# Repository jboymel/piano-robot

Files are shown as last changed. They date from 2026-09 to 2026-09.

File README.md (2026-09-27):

# Modular Robotic Actuation System for Piano Key Control

**A modular, clamp-on solenoid system that plays an acoustic piano from a MIDI score. Scaled from a one-octave prototype to a 7-octave (84-key) array of daisy-chained driver boards.**

Northwestern University · Summer Undergraduate Research Grant (SURG) 2026
Jordan Boymel · Advisor: Dr. Brenna Argall, Assistive & Rehabilitation Robotics Lab, Shirley Ryan AbilityLab

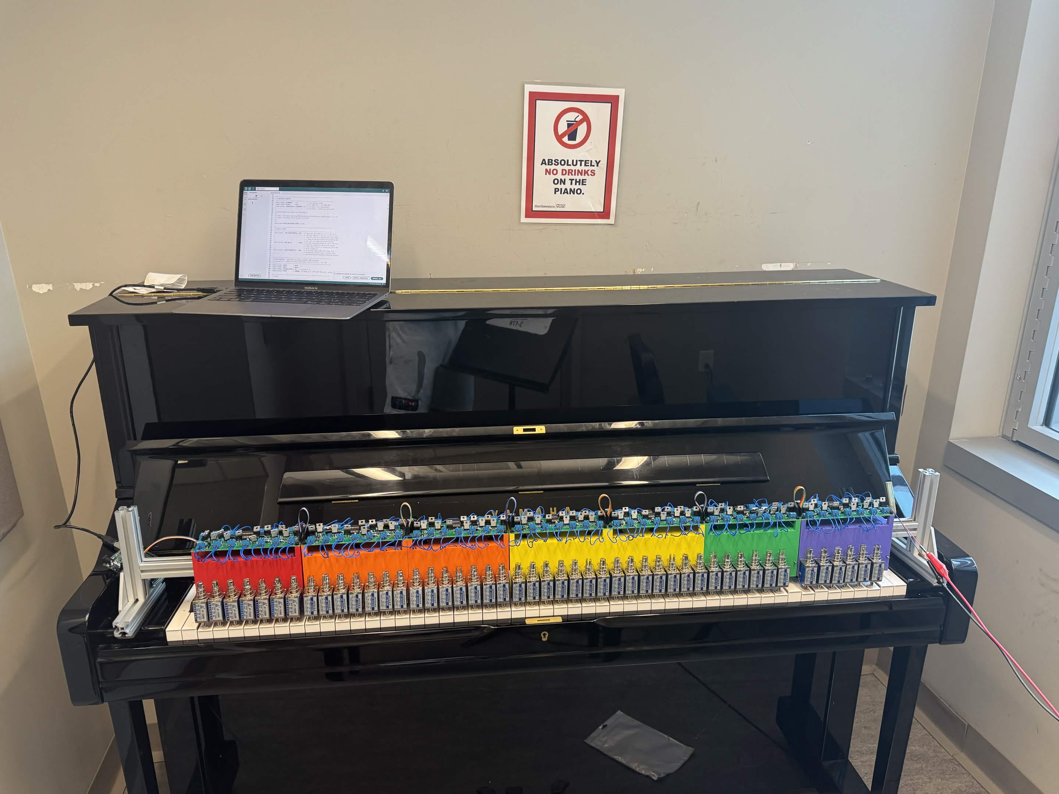
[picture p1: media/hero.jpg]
Robot mounted on the piano


> **Status (Sept 2026): hardware, firmware, and host software complete; full-scale tuning paused.**
> The whole pipeline, from MIDI to solenoids, runs. The final demo used a lower-rated 24 V supply because the main supply couldn't be wired properly, and several actuators strike inconsistently. See [Current status and known issues](#current-status-and-known-issues).

---

## Why

Self-playing pianos are purpose-built, expensive instruments. This project asks whether a modular attachment can turn an ordinary piano into a music-making machine instead. It is motivated by making piano playing accessible to people with motor disabilities, and by the number of acoustic pianos that sit unused.

## What I built

| Area | What it is |
|---|---|
| **Driver electronics** | Custom 2-layer KiCad PCB, one per octave: 12 low-side MOSFET channels, flyback protection, and a shift-register serial interface. Boards daisy-chain for power and signal. |
| **Actuation** | 24 V push-pull solenoids (one per key) with a threaded felt-tipped striker |
| **Mechanical** | Parametric Onshape bracket that straddles 80/20 T-slot extrusion over the keybed. Key pitch was measured on a real piano. |
| **Firmware** | Arduino Mega sketch that receives full keyboard state over USB serial and clocks it to the shift-register chain, with safety interlocks |
| **Host software** | Python player that reads a MuseScore MIDI export, compensates for actuator latency, and streams frames to the Arduino |

## System architecture

The Arduino connects to the whole 84-key array through five wires: 5 V, GND, DATA (pin 51), CLOCK (pin 52), and LATCH (pin 8).

## Hardware

### Octave driver board

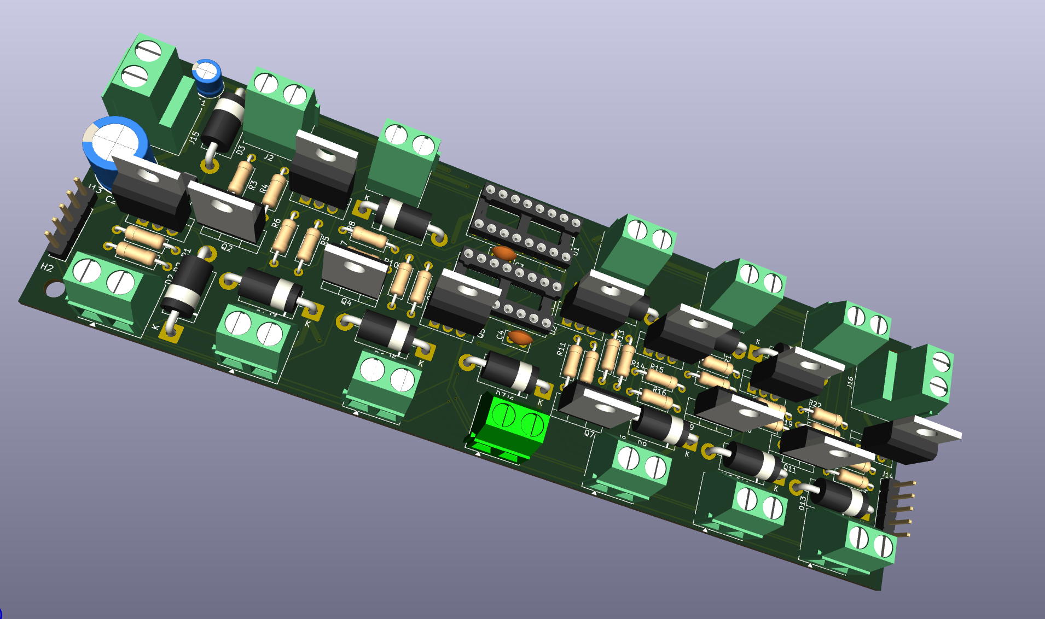
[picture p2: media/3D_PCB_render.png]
Octave driver board


- **163.8 × 52.4 mm**, 2-layer. Four M3 mounting holes on a 155.8 × 44.4 mm pattern.
- **Two 74HC595 shift registers** per board, in DIP sockets and cascaded (U1 QH′ → U2 SER). 12 of 16 outputs are used. SRCLR is tied high and OE is tied low.
- **12 × IRLZ44N** logic-level MOSFETs (55 V V<sub>DS</sub>), low-side switching, TO-220 mounted vertically to save board depth.
- **FR307 flyback diode** across each solenoid, and an SMBJ28A TVS diode for transient protection.
- Each MOSFET gate has a 220 Ω and a 10 kΩ resistor.
- GND pour on B.Cu and +24 V on F.Cu. Trace widths sized to IPC-2152 for solenoid current.
- **Power in/out:** screw terminals J15 → J16 pass the 24 V bus board-to-board on heavy wire. Logic signals chain separately on a 5-conductor ribbon.
- First spin fabricated by JLCPCB. Seven boards assembled.

### Actuators and strikers
- **JF-1039B** push-pull solenoid: 25 N, 10 mm stroke, about 400 mA at 24 V.
- **Striker:** an M4 × 0.7 coupling nut threads onto the plunger, with a 3/8″ felt pad on the contact face to protect the keys and soften the attack.

### Mounting bracket
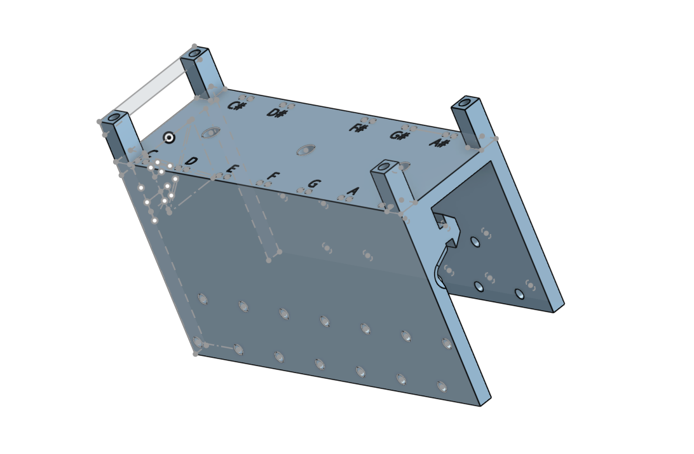
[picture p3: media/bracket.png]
Parametric bracket


- An asymmetric inverted-U saddle that straddles 80/20 T-slot extrusion. It is fully parametric in Onshape.
- Key pitch was measured on a real piano and adjusted from 23.4 mm to about 23.5 mm. The standoff inset is a parameter, so the bracket stays compatible with the PCB hole pattern.

### Power
- **24 V solenoid bus:** a single 1500 W (62.5 A) switching supply, chained board-to-board.
- **5 V logic:** supplied from the laptop over the Arduino's USB connection and carried to every board on the signal ribbon.
- All grounds are common.

## Firmware and control

### Serial protocol (host → Arduino)

| Field | Bytes | Value |
|---|---|---|
| Sync | 2 | `0xAA 0x55` |
| Key state | 11 | 84 bits, one per key (1 = energized) |
| Checksum | 1 | XOR |

Sent at 250000 baud. Every frame carries the full keyboard state. The Arduino never has to reconstruct note-on/note-off history, so a dropped frame is simply replaced by the next one.

### Safety limits (firmware)

| Limit | Value | Purpose |
|---|---|---|
| `MAX_SIMULTANEOUS` | 20 keys | Caps solenoid current at about 8 A |
| `MAX_ON_MS` | 5000 ms | Releases any key held too long, which protects the coils from overheating |
| `LINK_TIMEOUT_MS` | 500 ms | Releases all keys if the host stops sending valid frames |

### Latency compensation (host)
Measured strike latency is about 50 ms from energize to key contact. `musescore_player.py` schedules every note `ATTACK_LATENCY_MS` (≈50 ms) early so strikes land on the beat. It also enforces `MINIMUM_STRIKE_HOLD_MS` (≈10 ms) so very short notes still fully depress the key.

The latency also sets a mechanical limit: repeated notes on the same key top out around sixteenth notes at 95–100 BPM.

## Design evolution

The project started as a one-octave bench prototype focused on characterizing a single key. The table lists the major changes on the way to 84 keys.

| Change | Why |
|---|---|
| One Arduino pin per key → **74HC595 shift-register chain** | 84 keys can't each get a pin. Three signal lines now drive any number of boards. |
| IRLB8721 (30 V) → **IRLZ44N (55 V)** | More drain-voltage margin against inductive switching transients on a 24 V rail |
| 3-tier PCB stack → **2 tiers** | The FSR circuit was confirmed as instrumentation only, not part of the production drive path |
| One large board → **one PCB per octave, daisy-chained** | Identical boards are cheaper to fabricate, easier to debug, and scale to any number of octaves |
| Key pitch 23.4 mm → **≈23.5 mm** | Measured on a real piano. The error accumulates across an octave. |

Peer review of the schematics caught wiring errors before fabrication, including flyback diode polarity and MOSFET pinout.

## Current status and known issues

**Works**
- Seven octave boards assembled and running on one chain.
- Firmware, serial protocol, and safety limits are working.
- The Python player drives the array from MuseScore MIDI.
- The shift-register chain was validated with indicator LEDs before solenoids were connected.

**Resolved**
- **Chain failure when scaling from 3 to 7 boards.** The symptoms looked like a power-budget problem, but the cause was one shift register seated backwards in its socket. Write-up: [docs/power-debugging.md](docs/power-debugging.md).

**Known issues**
1. **Demo run on an underpowered 24 V supply.** The main 1500 W supply couldn't be wired in time for the final demo because the right-gauge wire was missing, so a lower-rated supply stood in.
2. **Inconsistent strikes on some actuators.** Not yet diagnosed. An under-supplied 24 V rail (issue 1) is the first suspect. Solenoid, striker, or mounting variation still has to be ruled out once the main supply is connected.

<!-- MEDIA: even an imperfect clip is worth including. Label it honestly, e.g.
**Demo (Sept 2026, reduced-power supply):** [video](media/demo.mp4)
-->

## Next steps
- Wire in the main 24 V supply and re-test all 84 channels.
- Diagnose the inconsistent actuators channel by channel (current draw, stroke, striker seating).
- Quantify timing and force consistency. The original proposal set targets (mean onset error under 10 ms, standard deviation under 5 ms, force coefficient of variation under 15%) and planned an FSR 402 and TCST2103 photointerrupter rig to measure them. That rig was prototyped on the bench but not used in the final build, and no characterization data has been collected yet.
- Record a clean full-keyboard demo.

## Lessons learned
- **Check the assembly before redesigning the system.** The failure at 7 boards looked like a supply problem, and I had started planning a separate 5 V supply. The actual cause was one reversed IC.
- **Scale in steps and test at each one.** Adding boards incrementally narrowed the fault to the new part of the chain.
- **Design reviews pay for themselves.** Wiring errors were caught on paper instead of on a powered board.

## Repository layout

```
firmware/
  piano_driver/        piano_driver.ino: Arduino Mega sketch (serial → shift-register chain)
  bench_test/          serial_logger.py: logger from the single-key bench prototype
host/                  midi_player.py: MIDI file → serial key-state frames
hardware/
  pcb/                 KiCad project (solenoid-driver-v2) and fabrication Gerbers (.zip)
cad/
  stl/                 bracket.stl
matlab/analysis/       analyze_trials.m: trial statistics (onset time, force)
docs/                  BOM, wiring, schematic PDF, chain-failure write-up
media/                 Photos, KiCad render, test videos
```

> `matlab/analysis/analyze_trials.m` generates **placeholder data** if no real trial CSV is present. Any plots it produces without real data are not results.

## Bill of materials and wiring
- [Bill of materials](docs/bom.md)
- [Prototype bench wiring](docs/wiring.md)
- [Debugging the 7-board chain failure](docs/power-debugging.md)

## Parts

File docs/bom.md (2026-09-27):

# Bill of materials

## Per octave driver board (×7)

| Item | Spec | Qty per board |
|---|---|---|
| Octave driver PCB | 2-layer, 163.8 × 52.4 mm (JLCPCB) | 1 |
| 74HC595 shift register (U1, U2) | 8-bit SIPO, DIP-16 | 2 |
| IRLZ44N MOSFET (Q1–Q12) | TO-220, logic-level, 55 V V<sub>DS</sub>, mounted vertically | 12 |
| DIP-16 socket | For U1, U2 | 2 |
| FR307 flyback diode (D2–D13) | 3 A fast recovery, DO-201AD | 12 |
| SMBJ28A TVS diode (D1) | 28 V standoff, SMB (the only SMD part) | 1 |
| Resistor, 220 Ω | Axial, one per MOSFET gate | 12 |
| Resistor, 10 kΩ | Axial, one per MOSFET gate | 12 |
| Capacitor, 1000 µF (C2) | Electrolytic, radial 10 mm | 1 |
| Capacitor, 10 µF (C1) | Electrolytic, radial 5 mm | 1 |
| Capacitor, 0.1 µF (C3, C4) | Ceramic disc | 2 |
| Screw terminal, solenoid (J1–J12) | Phoenix MKDS 1,5 style, 2-pos, 5.08 mm | 12 |
| Screw terminal, power (J15, J16) | Phoenix MKDS 3 style, 2-pos, 5.08 mm; 24 V / GND in and out | 2 |
| 1×5 pin header (J13, J14) | 2.54 mm; 5 V · GND · DATA · CLOCK · LATCH in and out | 2 |
| JF-1039BS solenoid | 24 V push-pull, 25 N, 10 mm stroke, ~400 mA | 12 |
| M4 × 0.7 coupling nut | Round, 10 mm, female-female (striker) | 12 |
| Felt pad | 3/8″ adhesive dot (striker face) | 12 |

## System

| Item | Spec | Qty |
|---|---|-----|
| 24 V switching PSU | 1500 W, 62.5 A | 1 |
| Arduino Mega 2560 | USB-powered; also supplies 5 V logic to all boards | 1 |
| 80/20 1010 T-slot extrusion | Frame rail | as needed |
| Bracket | Parametric, 3D-printed PLA | as needed |
| Silicone protection | Applied to the frame | as needed |

## Prototype bench only (not used in the final build)

| Item | Spec | Qty |
|---|---|-----|
| FSR 402 | Force sensing resistor | 2 |
| TCST2103 | Slotted photointerrupter (onset timing) | 6 |

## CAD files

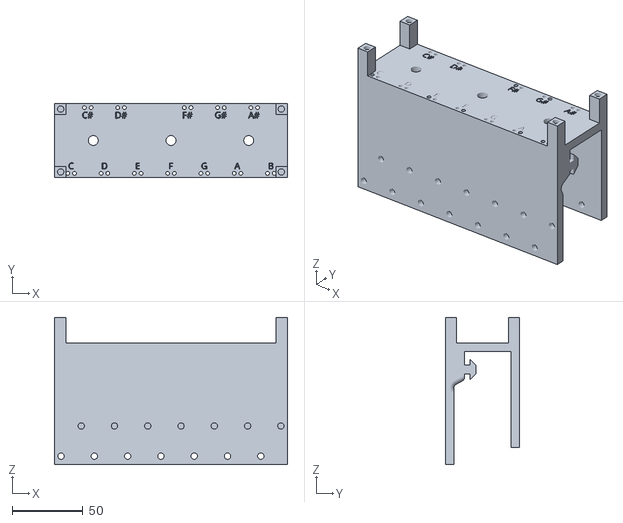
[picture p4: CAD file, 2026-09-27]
cad/stl/bracket.stl
164.5 x 52.4 x 104.0

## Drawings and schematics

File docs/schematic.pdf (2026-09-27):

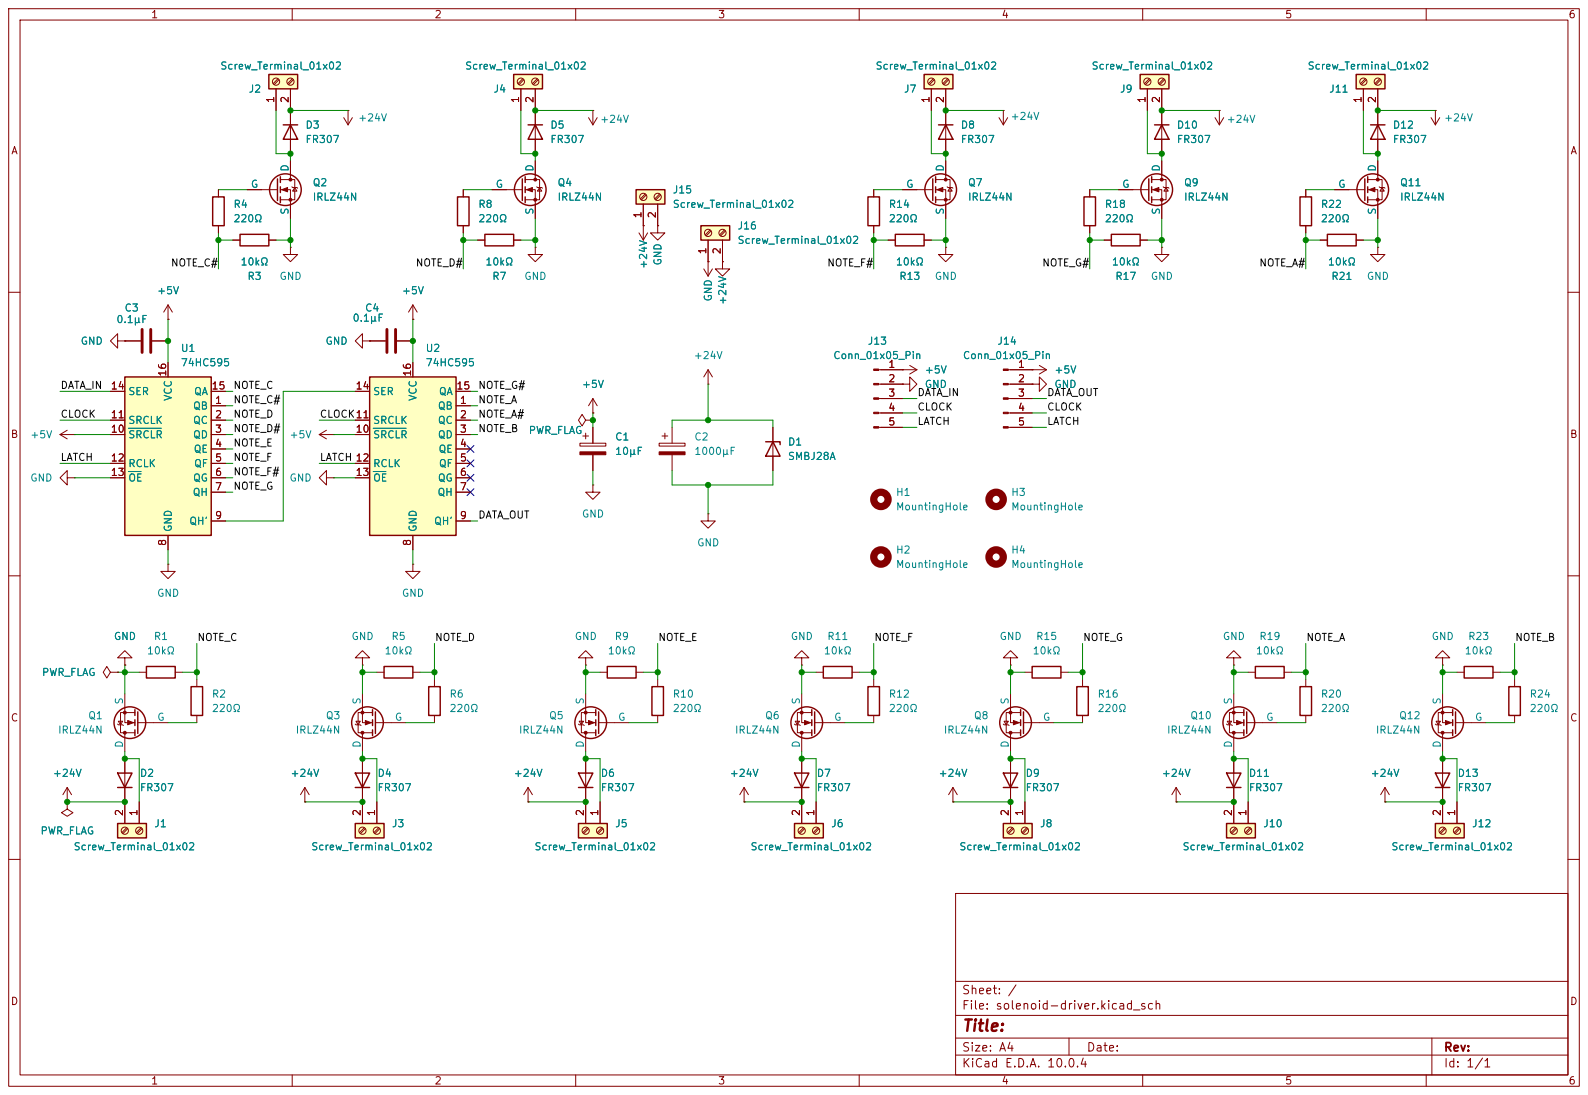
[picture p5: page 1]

SRCLR 10 SRCLK 11 RCLK 12 OE 13

Size: A4 | Rev:
KiCad E.D.A. 10.0.4 | Id: 1/1

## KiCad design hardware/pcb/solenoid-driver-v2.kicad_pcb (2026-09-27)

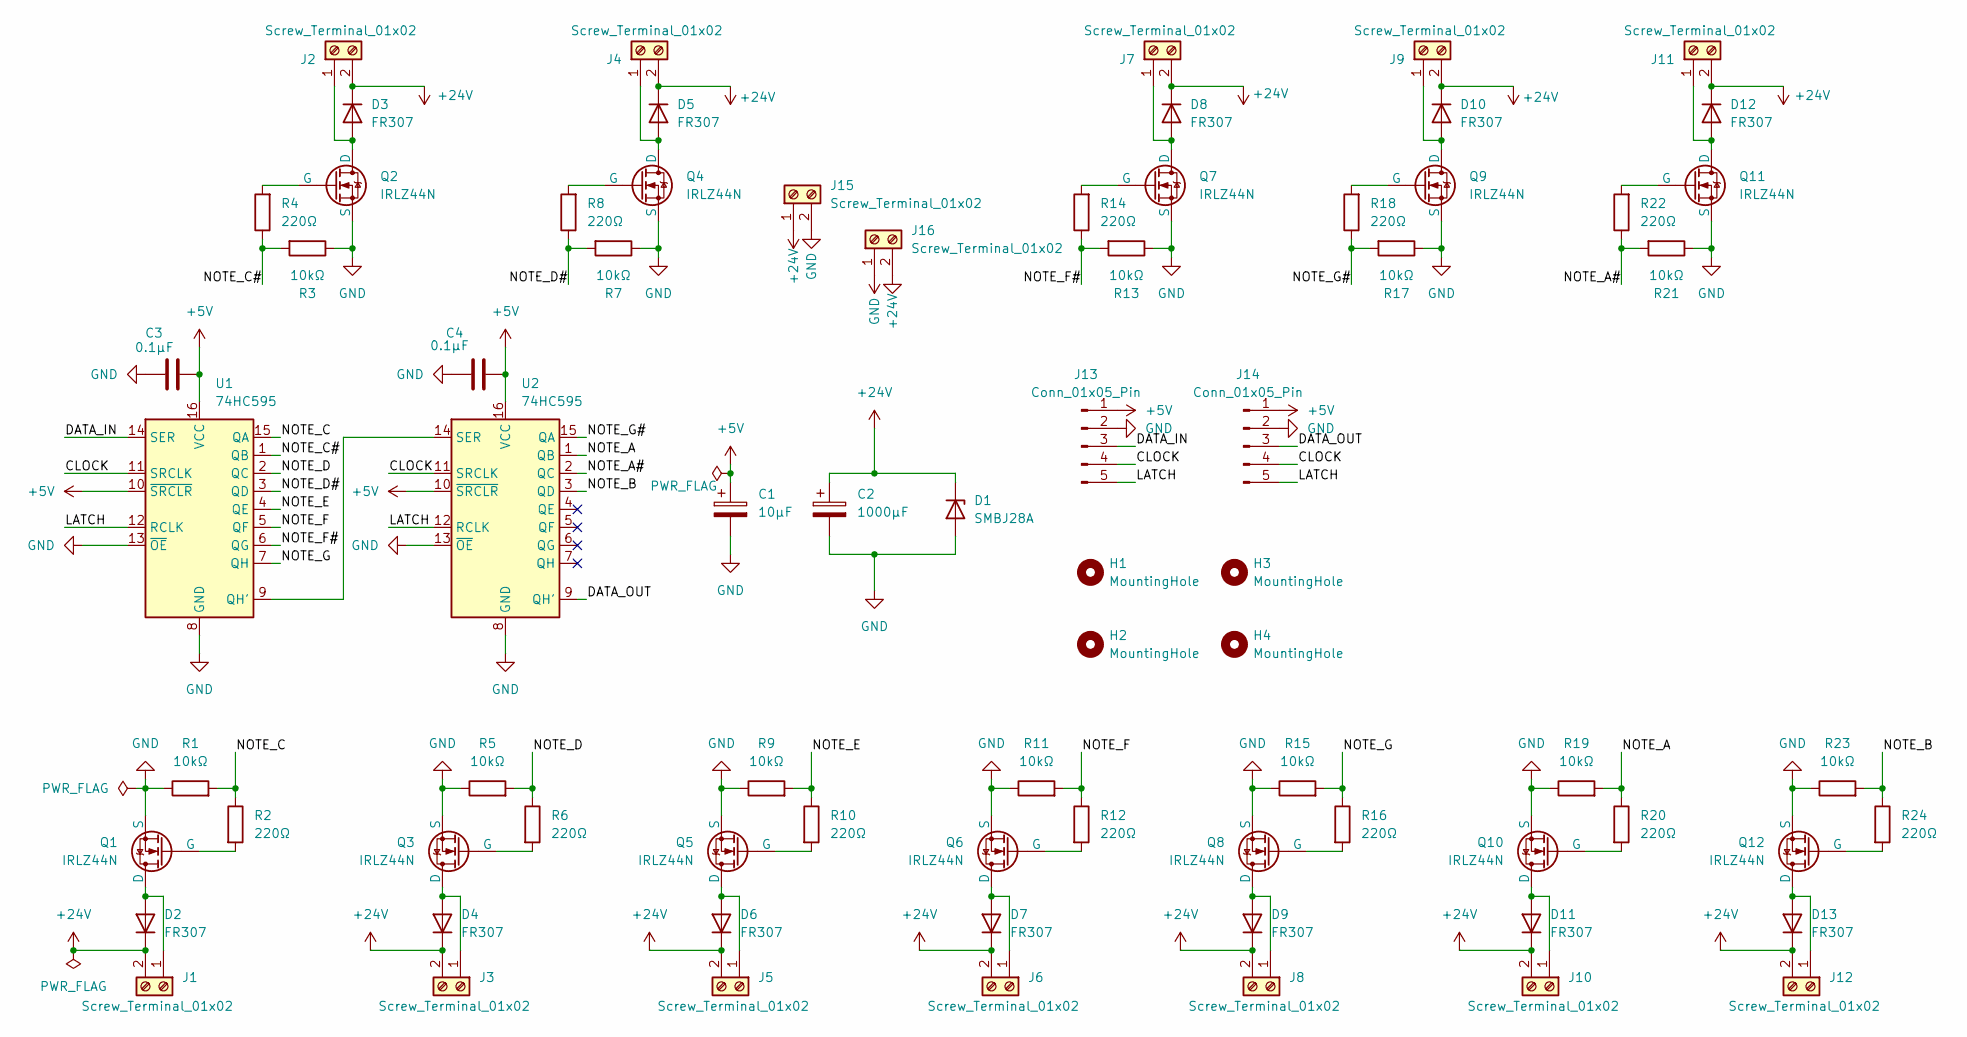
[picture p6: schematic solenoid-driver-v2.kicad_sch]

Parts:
C1: 10µF; CP_Radial_D5.0mm_P2.00mm
C2: 1000µF; CP_Radial_D10.0mm_P5.00mm
C3, C4: 0.1µF; C_Disc_D5.0mm_W2.5mm_P2.50mm
D1: SMBJ28A; D_SMB
D2, D3, D4, D5, D6, D7, D8, D9, D10, D11, D12, D13: FR307; D_DO-201AD_P15.24mm_Horizontal
H1, H2, H3, H4: MountingHole; MountingHole_3.2mm_M3
J1, J2, J3, J4, J5, J6, J7, J8, J9, J10, J11, J12: Screw_Terminal_01x02; TerminalBlock_Phoenix_MKDS-1,5-2-5.08_1x02_P5.08mm_Horizont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
J13, J14: Conn_01x05_Pin; PinHeader_1x05_P2.54mm_Vertical
J15, J16: Screw_Terminal_01x02; TerminalBlock_Phoenix_MKDS-3-2-5.08_1x02_P5.08mm_Horizontal
Q1, Q2, Q3, Q4, Q5, Q6, Q7, Q8, Q9, Q10, Q11, Q12: IRLZ44N; TO-220-3_Vertical
R1, R3, R5, R7, R9, R11, R13, R15, R17, R19, R21, R23: 10kΩ; R_Axial_DIN0207_L6.3mm_D2.5mm_P10.16mm_Horizontal
R2, R4, R6, R8, R10, R12, R14, R16, R18, R20, R22, R24: 220Ω; R_Axial_DIN0207_L6.3mm_D2.5mm_P10.16mm_Horizontal
U1, U2: 74HC595; DIP-16_W7.62mm_Socket

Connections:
+5V: C1.1, C3.2, C4.2, J13.1, J14.1, U1.10 (~SRCLR), U1.16 (VCC), U2.10 (~SRCLR), U2.16 (VCC)
+24V: C2.1, D1.1 (K), D2.1 (K), D3.1 (K), D4.1 (K), D5.1 (K), D6.1 (K), D7.1 (K), D8.1 (K), D9.1 (K), D10.1 (K), D11.1 (K), D12.1 (K), D13.1 (K), J1.2, J2.2, J3.2, J4.2, J5.2, J6.2, J7.2, J8.2, J9.2, J10.2, J11.2, J12.2, J15.1, J16.2
/CLOCK: J13.4, J14.4, U1.11 (SRCLK), U2.11 (SRCLK)
/DATA_IN: J13.3, U1.14 (SER)
/DATA_OUT: J14.3, U2.9 (QH')
/LATCH: J13.5, J14.5, U1.12 (RCLK), U2.12 (RCLK)
/NOTE_A: R19.2, R20.1, U2.1 (QB)
/NOTE_A#: R21.2, R22.1, U2.2 (QC)
/NOTE_B: R23.2, R24.1, U2.3 (QD)
/NOTE_C: R1.2, R2.1, U1.15 (QA)
/NOTE_C#: R3.2, R4.1, U1.1 (QB)
/NOTE_D: R5.2, R6.1, U1.2 (QC)
/NOTE_D#: R7.2, R8.1, U1.3 (QD)
/NOTE_E: R9.2, R10.1, U1.4 (QE)
/NOTE_F: R11.2, R12.1, U1.5 (QF)
/NOTE_F#: R13.2, R14.1, U1.6 (QG)
/NOTE_G: R15.2, R16.1, U1.7 (QH)
/NOTE_G#: R17.2, R18.1, U2.15 (QA)
GND: C1.2, C2.2, C3.1, C4.1, D1.2 (A), J13.2, J14.2, J15.2, J16.1, Q1.3 (S), Q2.3 (S), Q3.3 (S), Q4.3 (S), Q5.3 (S), Q6.3 (S), Q7.3 (S), Q8.3 (S), Q9.3 (S), Q10.3 (S), Q11.3 (S), Q12.3 (S), R1.1, R3.1, R5.1, R7.1, R9.1, R11.1, R13.1, R15.1, R17.1, R19.1, R21.1, R23.1, U1.8 (GND), U1.13 (~OE), U2.8 (GND), U2.13 (~OE)
unnamed: D2.2 (A), J1.1, Q1.1 (D)
unnamed: D3.2 (A), J2.1, Q2.1 (D)
unnamed: D4.2 (A), J3.1, Q3.1 (D)
unnamed: D5.2 (A), J4.1, Q4.1 (D)
unnamed: D6.2 (A), J5.1, Q5.1 (D)
unnamed: D7.2 (A), J6.1, Q6.1 (D)
unnamed: D8.2 (A), J7.1, Q7.1 (D)
unnamed: D9.2 (A), J8.1, Q8.1 (D)
unnamed: D10.2 (A), J9.1, Q9.1 (D)
unnamed: D11.2 (A), J10.1, Q10.1 (D)
unnamed: D12.2 (A), J11.1, Q11.1 (D)
unnamed: D13.2 (A), J12.1, Q12.1 (D)
unnamed: Q1.2 (G), R2.2
unnamed: Q2.2 (G), R4.2
unnamed: Q3.2 (G), R6.2
unnamed: Q4.2 (G), R8.2
unnamed: Q5.2 (G), R10.2
unnamed: Q6.2 (G), R12.2
unnamed: Q7.2 (G), R14.2
unnamed: Q8.2 (G), R16.2
unnamed: Q9.2 (G), R18.2
unnamed: Q10.2 (G), R20.2
unnamed: Q11.2 (G), R22.2
unnamed: Q12.2 (G), R24.2
unnamed: U1.9 (QH'), U2.14 (SER)

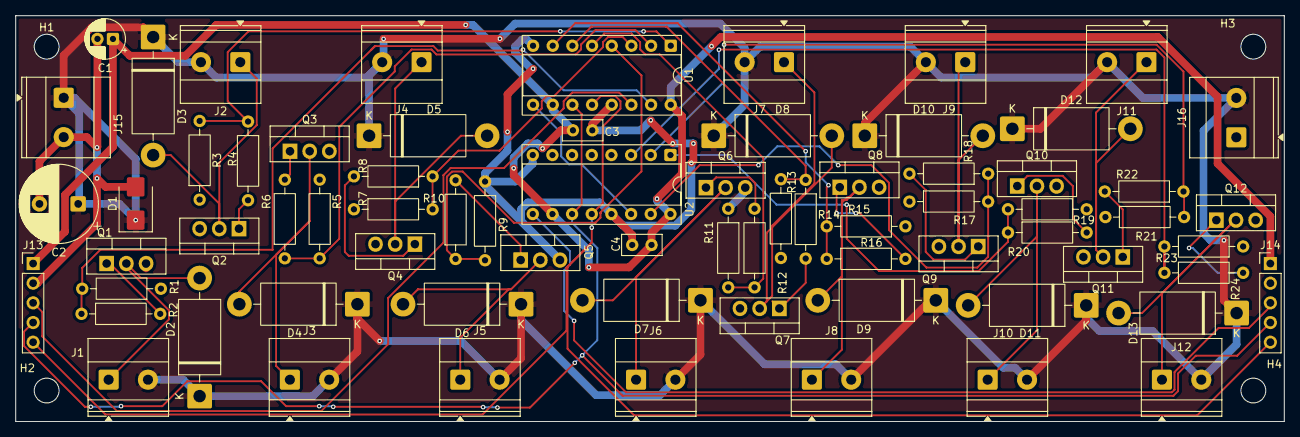
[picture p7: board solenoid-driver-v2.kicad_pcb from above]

Board: 2 copper layers, 163.8 x 52.4 mm, 75 parts (0 on the bottom side), 44 nets.

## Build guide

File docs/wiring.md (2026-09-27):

# Wiring

This page covers the final 84-key system: seven identical octave boards, driven by an Arduino Mega. Part values and designators match the [BOM](bom.md).

## Overview

The laptop connects to the Arduino over USB, which carries both serial data and 5 V power. The Arduino drives Board 1, and two separate chains run from each board to the next:
- **Signal chain:** 5-conductor ribbon between the 1×5 headers (J13 in, J14 out).
- **Power chain:** heavy wire between the 2-position power screw terminals (J15 in, J16 out). The 24 V supply connects to Board 1's J15.

## Arduino Mega → Board 1

| Arduino pin | Signal | Notes |
|---|---|---|
| 51 (MOSI) | DATA | Hardware SPI |
| 52 (SCK) | CLOCK | Hardware SPI |
| 8 | LATCH | 74HC595 RCLK |
| 5V | 5 V logic | Powers the shift registers on all 7 boards |
| GND | GND | Common with the 24 V supply ground |

The 5 V logic rail for the entire chain comes from the laptop's USB through the Arduino. No separate 5 V supply is used.

## Shift-register chain (per board)

- **U1 → U2:** U1's serial out (QH′) feeds U2's serial in (SER).
- **Board → board:** U2's QH′ leaves on the DATA line of the outgoing ribbon and feeds U1 SER on the next board. CLOCK and LATCH are shared by every board.
- **SRCLR** is tied to +5 V (never cleared). **OE** is tied to GND (outputs always enabled).
- 12 of U1/U2's 16 outputs drive MOSFET gates. The other 4 are unused.
- Both 74HC595s sit in DIP-16 sockets. Check the pin-1 notch when you insert them (see [the chain-failure write-up](power-debugging.md)).

Across 7 boards this forms one 112-bit shift chain. 84 of those bits are keys.

## Solenoid channel (×12 per board)

- **Gate:** 220 Ω series resistor from the 74HC595 output, and a 10 kΩ pull-down to GND that holds the MOSFET off while the logic is unpowered or floating.
- **Drain:** one side of the solenoid (through its screw terminal) and the FR307 anode.
- **Source:** GND.
- **Solenoid:** the other side goes to +24 V.
- **FR307 flyback diode:** cathode (stripe) at +24 V, anode at the drain. It clamps the inductive kick when the MOSFET turns off.
- **IRLZ44N pinout** (TO-220, flat face toward you): Gate · Drain · Source, left to right.

## Power

- A single 24 V, 1500 W (62.5 A) switching supply feeds Board 1's J15. Each board's J16 feeds the next board's J15.
- Each solenoid draws about 400 mA. Firmware caps simultaneous keys at 20, which is about 8 A on the bus.
- Common ground: the 24 V supply ground, the board grounds, and the Arduino ground are all tied together.
- On-board protection and bulk capacitance: SMBJ28A TVS diode (D1), 1000 µF (C2) and 10 µF (C1) electrolytic, and 0.1 µF ceramic (C3, C4). See the KiCad schematic for placement.

---

## Prototype (superseded)

Before the octave boards, a single-key bench circuit drove one IRLZ44N directly from an Arduino PWM pin (100 Ω gate resistor, 10 kΩ pull-down). The flyback arrangement was the same as above. The bench also included an FSR 402 and a TCST2103 photointerrupter for planned force and timing measurements. These were not used in the final build, and no data was collected with them. The direct-drive approach needed one Arduino pin per key, which is why the design moved to the shift-register chain.

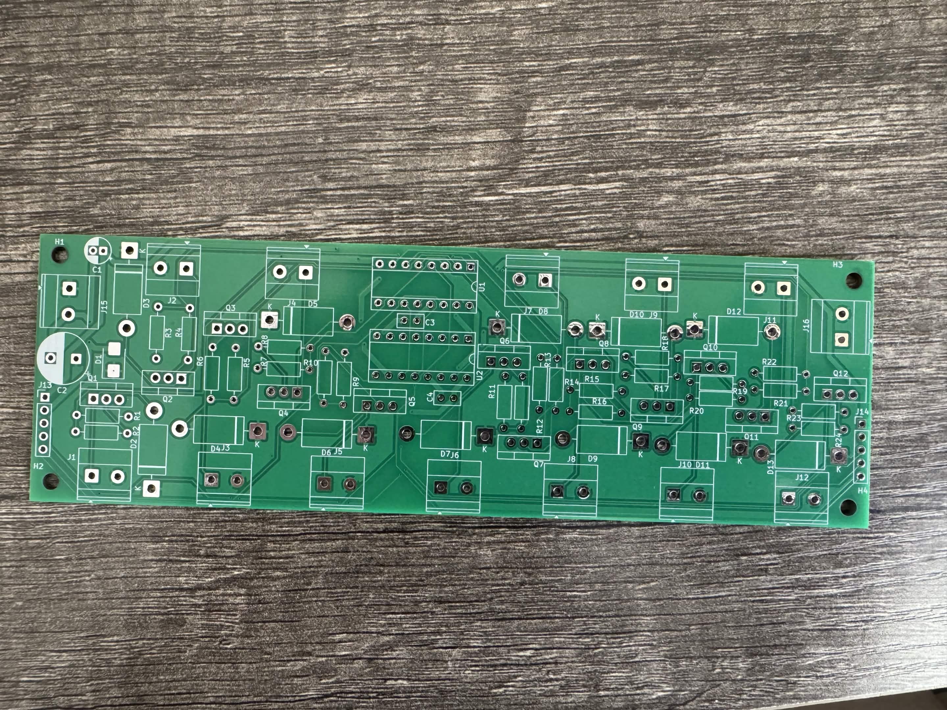
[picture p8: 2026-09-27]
media/unassembled_PCB.jpg

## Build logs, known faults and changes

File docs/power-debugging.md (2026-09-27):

# Debugging the 7-board chain failure

## Symptom
Three octave boards chained together worked as expected: shift-register outputs were verified with indicator LEDs. With all seven boards connected, the system stopped working reliably. The 5 V logic rail sagged along the chain, from 5.0 V at the first board to about 4 V or lower at the far end, and the Arduino browned out.

## First hypothesis: power budget (wrong)
The symptoms pointed to an undersized logic supply. The 5 V rail came from the laptop through the Arduino's USB port, which supplies about 500 mA, and it was daisy-chained to every board through the 1×5 signal headers. The theory was that 7 boards' worth of logic load, plus the voltage drop across six header connections, exceeded what USB could supply.

I planned a fix to match: a dedicated external 5 V supply for the shift registers, with the Arduino's USB powering only the Mega. Before building that, I worked through a diagnostic checklist:

1. Confirm the Arduino still uploads and runs over USB with nothing attached.
2. Check continuity pin-to-pin across the 1×5 headers, and from VCC/GND to each shift register's pins.
3. Measure the 5 V rail at each board with the chain connected.

## Actual cause: one reversed 74HC595
One of the shift registers had been put in upside down. After it was reinstalled in the correct orientation, the problem went away. The full 7-board chain now runs from the laptop's USB 5 V, with no separate supply.

A CMOS IC installed backwards has its supply pins swapped with signal pins, and it can conduct heavily through its internal protection structures. That loads the rail, which matches the sag and brownouts seen here.

## Takeaways
- **Rule out assembly errors before redesigning.** The symptoms fit a power-budget story well enough that I nearly added a supply the system didn't need.
- **Scaling in steps localized the fault.** Three boards worked and seven didn't, which narrowed where to look.
- **Visual inspection is a cheap first check.** IC orientation (the pin-1 dot and notch against the silkscreen) takes seconds to verify on every board.

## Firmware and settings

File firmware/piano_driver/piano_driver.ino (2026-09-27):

/* ============================================================================
 * piano_driver.ino
 * 84-key (C1..B7) solenoid piano actuator
 *
 * Hardware: Arduino Mega 2560
 *           7 octave PCBs daisy-chained, 2x 74HC595 per board
 *           74HC595 outputs -> IRLZ44N gate (logic HIGH = solenoid energized)
 *           24 V solenoid rail, 400 mA/solenoid, ~65 A supply
 *
 * The Mega does no musical work. It receives a full 84-bit keyboard state from
 * the host over USB serial, applies safety limits, and clocks the chain.
 * All scheduling, tempo, and voice allocation happen in midi_player.py.
 * ========================================================================== */

#include <SPI.h>
#include <string.h>

/* ---------------------------------------------------------------------------
 * PIN MAP (Arduino Mega 2560)
 * ------------------------------------------------------------------------ */
const uint8_t PIN_DATA = 51;  // MOSI. Hardware SPI data out. Fixed by the
                              // ATmega2560 -- cannot be reassigned.
                              // Wire to DATA_IN (SER of U1 on the FIRST board).
const uint8_t PIN_CLOCK = 52; // SCK. Hardware SPI clock. Also fixed.
                              // Wire to CLOCK (SRCLK), bussed to all 14 registers.
const uint8_t PIN_LATCH = 8;  // Plain digital output (no PWM needed).
                              // Wire to LATCH (RCLK), bussed to all 14 registers.
const uint8_t PIN_SS = 53;    // SPI slave-select. NOT wired to anything, but it
                              // must be configured as an output or the AVR SPI
                              // peripheral silently drops out of master mode.
const uint8_t PIN_LED = 13;   // Onboard LED (PWM-capable, used as plain digital).
                              // Lit whenever any solenoid is energized.

/* ---------------------------------------------------------------------------
 * KEYBOARD GEOMETRY
 * ------------------------------------------------------------------------ */
const uint8_t N_BOARDS = 7;                // one PCB per octave
const uint8_t N_KEYS = N_BOARDS * 12;      // C1 (MIDI 24) .. B7 (MIDI 107)
const uint8_t CHAIN_BYTES = N_BOARDS * 2;  // 14 bytes = 112 clocked bits
                                           // (12 notes + 4 dead bits per board)

// the board receiving DATA_IN directly from the Mega drives octave 1 (C1..B1)


/* ---------------------------------------------------------------------------
 * SAFETY LIMITS
 * ------------------------------------------------------------------------ */
const uint8_t  MAX_SIMULTANEOUS = 20;    // hard cap. 20 * 400 mA = 8 A of the 65 A.
                                         // The host applies a musical version of this
                                         // cap; this one is a dumb backstop that keeps
                                         // a buggy or malicious host from browning out
                                         // the rail. It keeps the lowest 20 keys.
const uint32_t MAX_ON_MS = 5000;         // per-key continuous energize limit. Set this
                                         // from your solenoid's duty-cycle rating.
                                         // A key that trips it is locked off until the
                                         // host releases it.
const uint32_t LINK_TIMEOUT_MS = 500;    // if the host goes quiet this long, drop
                                         // everything to prevemt a python crash
                                         // mid-chord leaving solenoids energized forever.

/* ---------------------------------------------------------------------------
 * WIRE PROTOCOL   0xAA 0x55 <11 payload bytes> <XOR checksum>
 * payload bit i (LSB-first within each byte) = key i, 0 = C1 ... 83 = B7
 * ------------------------------------------------------------------------ */
const uint8_t SYNC0 = 0xAA;
const uint8_t SYNC1 = 0x55;
const uint8_t PAYLOAD_BYTES = 11;  // ceil(84 / 8)
const uint32_t BAUD = 250000;      // exact on a 16 MHz AVR (0% error, unlike 115200)

/* ---------------------------------------------------------------------------
 * STATE
 * ------------------------------------------------------------------------ */
bool requested[N_KEYS];    // what keys were asked for
bool energized[N_KEYS];    // what is actually being driven after safety limits
uint32_t onsetMs[N_KEYS];  // when each key was energized, for MAX_ON_MS
bool thermalLock[N_KEYS];  // key exceeded MAX_ON_MS, held off until released
uint32_t lastFrameMs = 0;
bool linkUp = false;

/* ---------------------------------------------------------------------------
 * pushChain()
 *
 * Shift-register bit order:
 *
 *   A 74HC595 moves SER -> QA -> QB -> ... -> QH -> QH'. The FIRST bit clocked
 *   out therefore travels FURTHEST down the chain. With U1.QH' feeding U2.SER,
 *   the first 8 bits sent land in U2 and the last 8 land in U1.
 *
 *   Per board, transmit order (first sent -> last sent) maps to:
 *     U2.QH U2.QG U2.QF U2.QE  U2.QD U2.QC U2.QB U2.QA
 *     U1.QH U1.QG U1.QF U1.QE  U1.QD U1.QC U1.QB U1.QA
 *
 *   From the schematic, U1.QA..QH = C C# D D# E F F# G
 *                       U2.QA..QD = G# A A# B, and U2.QE..QH are unconnected.
 *
 *   So the first byte out of each board pair is:
 *     bit7..bit4 = pad (the 4 unused outputs), bit3..bit0 = B A# A G#
 *   and the second byte is:
 *     bit7..bit0 = G F# F E D# D C# C
 *
 *   Equivalently: semitone s (0=C..11=B) occupies bit s of the low byte for
 *   s < 8, and bit (s-8) of the high byte for s >= 8.
 *
 *   Across boards, the same "first sent travels furthest" rule means the board
 *   physically LAST in the chain must be transmitted FIRST.
 * ------------------------------------------------------------------------ */
void pushChain() {
  uint8_t frame[CHAIN_BYTES];
  uint8_t idx = 0;

  for (uint8_t k = 0; k < N_BOARDS; k++) {
    uint8_t board = N_BOARDS - 1 - k;
    

    uint8_t hi = 0;  // U2: pad, pad, pad, pad, B, A#, A, G#
    uint8_t lo = 0;  // U1: G, F#, F, E, D#, D, C#, C

    for (uint8_t s = 0; s < 12; s++) {
      if (!energized[board * 12 + s]) {
        continue;
      }

      if (s < 8) {
        lo |= (uint8_t)(1 << s);
      } else  {
        hi |= (uint8_t)(1 << (s - 8));
      }
    }

    frame[idx++] = hi;   // must go out before lo
    frame[idx++] = lo;
  }

  SPI.beginTransaction(SPISettings(1000000, MSBFIRST, SPI_MODE0)); // 1 MHz is conservative for ribbon-cabled 74HC595s; could go higher

  for (uint8_t i = 0; i < CHAIN_BYTES; i++) {
    SPI.transfer(frame[i]);
  }
  SPI.endTransaction();

  digitalWrite(PIN_LATCH, HIGH); // RCLK is rising-edge triggered
  digitalWrite(PIN_LATCH, LOW);
}

/* ---------------------------------------------------------------------------
 * applySafety() -- turns `requested` into `energized`
 * ------------------------------------------------------------------------ */
void applySafety() {
  uint32_t now = millis();

  bool linkOk = linkUp && (now - lastFrameMs < LINK_TIMEOUT_MS);

  if (!linkOk) {
    memset(energized, 0, sizeof(energized));
    memset(thermalLock, 0, sizeof(thermalLock));
    return;
  }

  // A key that tripped MAX_ON_MS stays locked until the host actually releases it,
  // so it cannot turn back on immediately.
  for (uint8_t i = 0; i < N_KEYS; i++) {
    if (!requested[i]) {
      thermalLock[i] = false;
      onsetMs[i] = 0;
    }
  }

  uint8_t count = 0;
  for (uint8_t i = 0; i < N_KEYS; i++) {
    bool want = requested[i] && !thermalLock[i];

    if (want && count >= MAX_SIMULTANEOUS) {
      want = false;                       // backstop cap, bass-first
    } else if (want) {
      if (!energized[i]) {
        onsetMs[i] = now;                 // rising edge, start the clock
      } else if (now - onsetMs[i] > MAX_ON_MS) {
        thermalLock[i] = true;
        want = false;
      }
    }

    energized[i] = want;
    if (want) count++;
  }
}

/* ---------------------------------------------------------------------------
 * readSerial() -- non-blocking frame parser
 * ------------------------------------------------------------------------ */
void readSerial() {
  static uint8_t state = 0;
  static uint8_t buf[PAYLOAD_BYTES];
  static uint8_t n = 0;

  while (Serial.available()) {
    uint8_t b = Serial.read();

    switch (state) {
      case 0:
        if (b == SYNC0) {
          state = 1;
        }
        break;

      case 1:
        if (b == SYNC1) { 
          state = 2; 
          n = 0; 
        } else if (b == SYNC0) {
          state = 1; 
        } else { 
          state = 0; 
        }
        break;

      case 2:
        buf[n++] = b;
        if (n == PAYLOAD_BYTES) {
          state = 3;
        }
        break;

      case 3: {
        uint8_t sum = 0;
        for (uint8_t i = 0; i < PAYLOAD_BYTES; i++) {
          sum ^= buf[i];
        }

        if (sum == b) {
          for (uint8_t i = 0; i < N_KEYS; i++) {
            uint8_t byteIndex = i / 8;
            uint8_t bitIndex = i % 8;
            requested[i] = (buf[byteIndex] >> bitIndex) & 1;
          }
          lastFrameMs = millis();
          linkUp = true;
        }

        state = 0; // bad checksum: drop the frame, resync
        break;
      }
    }
  }
}

/* ------------------------------------------------------------------------ */
void setup() {
  pinMode(PIN_LATCH, OUTPUT);
  digitalWrite(PIN_LATCH, LOW);
  pinMode(PIN_SS, OUTPUT);
  pinMode(PIN_LED, OUTPUT);

  memset(requested, 0, sizeof(requested));
  memset(energized, 0, sizeof(energized));
  memset(onsetMs, 0, sizeof(onsetMs));
  memset(thermalLock, 0, sizeof(thermalLock));

  SPI.begin();
  pushChain();                            // flush power-up garbage out of the registers

  Serial.begin(BAUD);
}

void loop() {
  readSerial();
  applySafety();
  pushChain();   // ~112 us. Rewriting every pass is self-healing: a bit corrupted
                 // by noise on the ribbon cable is corrected within one loop.

  uint8_t on = 0;
  for (uint8_t i = 0; i < N_KEYS; i++) {
    if (energized[i]) {
      on++;
    }
  }
  digitalWrite(PIN_LED, on > 0 ? HIGH : LOW);
}

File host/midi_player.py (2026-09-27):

#!/usr/bin/env python3
"""
midi_piano_player.py

Reads a MIDI file (any number of tracks/parts) and streams key-state frames
to the piano_driver.ino Arduino over USB serial, using its wire protocol
unchanged:

    0xAA 0x55 <11 payload bytes> <XOR checksum>   @ 250000 baud
    payload bit i (LSB-first within each byte) = key i, 0 = C1 ... 83 = B7

All tracks/parts in the file are merged into one 84-key performance. Because
a physical piano key can only be in one state at a time, overlapping notes
on the same pitch from different parts are turned into explicit
release-then-restrike sequences rather than just being held "on" --
see build_key_timeline() below.

Install deps:
    pip install mido python-rtmidi pyserial

Usage:
    python midi_piano_player.py song.mid --port /dev/ttyACM0
    python midi_piano_player.py song.mid --port COM5 --attack-latency-ms 60 \
        --min-on-ms 40 --release-gap-ms 35
"""

import argparse
import time

import mido
import serial

# --- Protocol constants -- must match piano_driver.ino exactly, unchanged --
SYNC0 = 0xAA
SYNC1 = 0x55
N_KEYS = 84          # C1 (MIDI 24) .. B7 (MIDI 107)
PAYLOAD_BYTES = 11   # ceil(84/8)
BAUD = 250000

MIDI_LOW = 24        # C1
MIDI_HIGH = 107      # B7


def build_frame(active_keys):
    """Pack an iterable of key indices (0..83) into one wire frame. Unchanged."""
    payload = bytearray(PAYLOAD_BYTES)
    for k in active_keys:
        if 0 <= k < N_KEYS:
            payload[k >> 3] |= (1 << (k & 7))
    checksum = 0
    for b in payload:
        checksum ^= b
    return bytes([SYNC0, SYNC1]) + bytes(payload) + bytes([checksum])


def extract_note_intervals(path):
    """
    Merge every track/channel in the MIDI file into one list of
    (key, start_sec, end_sec) intervals -- one per actual musical note.

    note_on/note_off are paired per (channel, note number), so two
    different parts playing overlapping notes on the same pitch stay as
    separate, correctly-timed intervals instead of getting confused with
    each other.
    """
    mid = mido.MidiFile(path)
    open_notes = {}          # (channel, note) -> start_sec
    intervals = []           # (key, start_sec, end_sec)
    t = 0.0

    for msg in mid:  # mido merges all tracks, yielding correct absolute time
        t += msg.time
        if msg.type == "note_on" and msg.velocity > 0:
            open_notes[(msg.channel, msg.note)] = t
        elif msg.type == "note_off" or (msg.type == "note_on" and msg.velocity == 0):
            start = open_notes.pop((msg.channel, msg.note), None)
            if start is None:
                continue  # note_off with no matching note_on -- ignore
            note = msg.note
            if MIDI_LOW <= note <= MIDI_HIGH:
                intervals.append((note - MIDI_LOW, start, t))

    return intervals


def build_key_timeline(intervals, attack_latency_ms, min_on_ms,
                        release_gap_ms, onset_merge_ms):
    """
    Turn the raw musical note intervals into physically valid actuator
    segments, one key at a time.

    Because a key can only be in one physical state, several rules apply
    when more than one part wants the same pitch:

      * Two notes starting within `onset_merge_ms` of each other are
        treated as one simultaneous attack (e.g. two parts striking a
        unison chord tone together) -- they share a single strike rather
        than re-triggering.
      * If a new note-on for a key arrives WHILE a previous note on that
        same key is still supposed to be sounding, the previous note is
        force-cut short -- released just long enough before the new
        strike to satisfy `release_gap_ms` -- so the new note gets its
        own attack transient at (approximately) its own notated onset,
        instead of being queued to start only after the held note's full
        duration finishes.
      * Every strike is held for at least `min_on_ms`, regardless of the
        notated musical duration (a mechanical minimum, not a musical one).
        This floor can delay a re-strike past its notated onset if the
        previous note hadn't been held long enough yet to be released.
      * `release_gap_ms` of off-time is always guaranteed between one
        strike's release and the next strike on the same key.

    Returns a flat, time-sorted list of [time_ms, key, is_on] events.
    """
    by_key = {}
    for key, start, end in intervals:
        by_key.setdefault(key, []).append((start * 1000.0, end * 1000.0))

    events = []
    for key, notes in by_key.items():
        notes.sort(key=lambda n: n[0])

        # Merge near-simultaneous onsets (different parts striking the
        # same pitch at effectively the same instant) into one note.
        merged = []
        for on_ms, off_ms in notes:
            if merged and on_ms - merged[-1][0] <= onset_merge_ms:
                merged[-1] = (merged[-1][0], max(merged[-1][1], off_ms))
            else:
                merged.append((on_ms, off_ms))

        cur_on = None          # actual strike time of the held segment
        cur_musical_off = None # its notated (un-adjusted) note-off

        for on_ms, off_ms in merged:
            intended_strike = on_ms - attack_latency_ms

            if cur_on is None:
                cur_on = intended_strike
                cur_musical_off = off_ms
                continue

            # Latest moment the held note could release and still leave a
            # full release_gap before this new note's intended strike.
            required_release_deadline = intended_strike - release_gap_ms

            # Cut the held note off at that deadline -- but never before
            # its own mechanical min-on floor, and never later than its
            # own natural musical end (don't artificially stretch a note
            # that already finished with plenty of gap to spare).
            actual_off = max(
                cur_on + min_on_ms,
                min(required_release_deadline, cur_musical_off),
            )

            # The new strike happens at its own intended time, unless the
            # min-on floor above forced a later release than that allows.
            new_on = max(intended_strike, actual_off + release_gap_ms)

            events.append([cur_on, key, True])
            events.append([actual_off, key, False])

            cur_on = new_on
            cur_musical_off = off_ms

        # Finalize whichever segment is still open at the end.
        final_off = max(cur_on + min_on_ms, cur_musical_off)
        events.append([cur_on, key, True])
        events.append([final_off, key, False])

    events.sort(key=lambda e: (e[0], e[1]))
    return events
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

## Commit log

2026-06-17 Initial repo structure: README, BOM, wiring docs, folder layout, gitignore
2026-06-30 Update README: correct MOSFET part number, actual actuator behavior
2026-09-27 removed flow chart from readme
2026-09-27 added bracket image
